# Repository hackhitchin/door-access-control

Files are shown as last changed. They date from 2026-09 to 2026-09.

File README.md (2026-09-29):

# Door Access Controller

Arduino Nano based door-control firmware for the Hack Hitchin access-control
system.

The Nano does **not** authenticate RFID cards. Credential verification is
handled separately by the ESP-RFID Blue Board. The Nano is responsible for the
door-control state machine, sensor handling, timing and the Utopic lock
interface.

This project is being developed with an emphasis on:

- predictable behaviour;
- explicit failure handling;
- simple hardware interfaces;
- host-side automated testing;
- code that remains approachable to future hackspace maintainers.

> **Not yet ready for deployment on the real door.**
>
> The FSM/controller are under automated test and CI compiles the complete classic
> Nano target. Hardware bench test and installation validation are still to be
> completed.

## Architecture

The firmware is split into three layers:

```text
physical inputs / millis()
          |
          v
DoorController
- debounce
- edge qualification
- startup handling
- timeout generation
          |
          v
DoorFsm
- states
- transitions
- faults
- retry policy
          |
          v
LockCommand
          |
          v
Arduino GPIO / relays
```

The FSM contains door-control policy. The surrounding controller converts raw,
debounced inputs and elapsed time into FSM events. The `.ino` file is intended
to remain a thin Arduino hardware adapter.

## FSM

The state machine uses ETL `state_chart`.

States:

- `LockedClosed`
- `Unlocking`
- `UnlockRetryWait`
- `UnlockedClosed`
- `Locking`
- `LockRetryWait`
- `UnlockedOpen`
- `Disabled`
- `Error`

There is deliberately no normal `LockedOpen` state. The bolt sensor is only
considered reliable when the door is closed; door-open plus bolt-locked is
treated as a contradictory physical/sensor condition.

### Motor commands

Motor output is derived from FSM state:

```text
Locking    -> Lock
Unlocking  -> Unlock
everything else -> None
```

The lock and unlock outputs are never intentionally asserted together.

During a retry wait the command is `None`. Unlock retries wait 1 s; lock
retries use the configured 1/10/100/1000/10000 s back-off.

A release request received during an in-flight lock operation is queued. The
controller waits for that lock command to confirm or time out, then unlocks
instead of accepting the locked state or starting another lock retry.

## Faults

Current fault codes are:

- `DoorOpenBoltLocked`
- `LockFailed`
- `UnlockFailed`
- `DoorOpenTooLong`
- `InvalidMode`

Entering `Error` removes the lock/unlock motor command.

Faults are not persisted across reset. A fault that is still physically present
after reboot should be detected again from the current inputs.

Where the underlying fault clears and a valid physical state can be
reconstructed, the FSM can return to normal operation without retaining the old
fault.

## Operating modes

The planned three-position maintained key switch has two signal inputs:

```text
D8  Standard
D9  Open Night
```

with pull-ups and contacts that pull the selected input LOW.

Logical encoding:

```text
D8  D9
HIGH HIGH  Disabled
LOW  HIGH  Standard
HIGH LOW   Open Night
LOW  LOW   Invalid / wiring fault
```

`Disabled` currently means no electronic lock or unlock commands. In
particular, the exit button is currently ignored in Disabled mode; this remains
a behaviour item to revisit if required.

## Inputs

Current Nano signal map:

```text
D2  lock-state sensor       active LOW
D3  exit button             active LOW
D4  door-closed reed        active LOW
D7  BlueBoard RFID release  active LOW
D8  Standard-mode contact   active LOW
D9  Open-Night contact      active LOW
```

Debounce times:

```text
door          30 ms
bolt          20 ms
RFID          10 ms
exit button   30 ms
mode switch   1000 ms
```

RFID and exit-button requests intentionally have different boot behaviour:

- RFID already active at boot is ignored until it first becomes inactive;
- an exit button already held at boot is honoured when electronic control is
  enabled.

At power-up the complete raw input set must remain unchanged for 100 ms before
controller construction, but this qualification wait is capped at 2 s so a
chattering input cannot prevent boot indefinitely.

## Outputs

Current relay mapping:

```text
A3 -> RL4 -> Utopic puck T1 -> lock
A2 -> RL3 -> Utopic puck T2 -> unlock
A1 -> RL2 -> FAULT connector
A0 -> RL1 -> BlueBoard "Button" contacts
```

Driving A3 or A2 HIGH energises the corresponding relay and pulls the Utopic
puck input LOW.

The Arduino hardware adapter uses break-before-make when changing lock command:
after either motor relay is released, the opposite relay cannot energise for
250 ms. This dead time is retained across intermediate `None` commands.

The FAULT relay is active for any FSM fault and also after the second failed
lock attempt while the longer retry back-off continues. A later successful lock
clears this degraded indication.

## Timing

Current parameters:

```text
Standard auto-lock        5 s
Open Night period         2 h
door-open warning         30 s
maximum door-open time    5 min Standard / 2 h Open Night
lock attempt timeout      5 s
unlock attempt timeout    5 s
lock retry delays         1 s, 10 s, 100 s, 1000 s, 10000 s
maximum lock retries      5
unlock retry delay        1 s
maximum unlock retries    2
```

Retry counts are retries **after** the initial attempt. Locking now uses five
back-off retries; unlocking retains two 1 s retries.

Timing code uses unsigned `uint32_t` subtraction so it remains correct across
Arduino `millis()` rollover.

## Testing

Native host tests use Unity and run in GitHub Actions on Ubuntu.

The FSM test suite covers:

- normal transitions;
- explicit retry-wait states;
- manual lock/unlock;
- mode transitions;
- fault entry;
- retry exhaustion;
- fault recovery;
- representative end-to-end sequences;
- state/event safety checks.

The established FSM coverage is:

```text
lines       100%
functions   100%
branches    88.9% (combined FSM + controller measurement before review fixes)
```

The remaining uncovered branches are compiler-generated short-circuit paths
that correspond to unreachable/redundant state combinations. CI therefore
requires:

```text
lines       100%
functions   100%
branches    >= 88%
```

A separate controller/wrapper test suite exercises debounce, startup handling,
RFID boot qualification, timeout generation, stale-timer cancellation,
same-tick ordering and `millis()` rollover.

CI builds and runs the FSM and controller test executables before collecting
combined coverage, and separately compiles the complete sketch for a classic
Arduino Nano with pinned AVR-core and ETL versions.

Third-party Unity/ETL code and test sources are excluded from project coverage.

For controlled bench commissioning, defining `DOOR_SERIAL_DIAGNOSTICS=1` in the
sketch enables a compact 115200-baud status line once per second. It reports
time, numeric state/mode/fault/command values, fault indication and debounced
input levels. It is disabled by default; opening USB serial may reset the Nano
via DTR.

## Repository layout

The intended source layout is:

```text
door-access-control/
├── door-access-control.ino
├── src/
│   ├── controller_config.h
│   ├── controller_types.h
│   ├── debounce.h
│   ├── door_controller.cpp
│   ├── door_controller.h
│   ├── door_fsm.cpp
│   ├── door_fsm.h
│   └── pin_defs.h
├── test/
│   ├── test_all.cpp
│   ├── test_controller.cpp
│   └── test_helpers.h
├── docs/
├── reference/
├── hardware/
├── mechanical/
└── .github/
    └── workflows/
        └── tests.yml
```

There should be one canonical copy of each source file. The Arduino sketch
includes the files in `src/`; source files are not duplicated in a separate
Arduino directory.

## Dependencies

- Arduino Nano / ATmega328P
- Embedded Template Library (ETL), using `etl::state_chart`
- Unity test framework for native tests
- LCOV/GCOV for CI coverage

ETL is downloaded by the GitHub Actions test workflow. Unity is kept in the
repository under `third_party/unity`.

## Hardware still outside the firmware

The following are deliberately not part of the current door-control firmware:

- optional backup maglock;
- independent watchdog / monitoring system;
- email or remote fault notification;
- persistent fault history.

These should remain separate from the safety-critical FSM unless their
interfaces are explicitly defined and tested.

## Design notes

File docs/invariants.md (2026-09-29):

# Door Controller System Invariants

Status: Draft v1  
Project: Hitchin Hackspace door access system

This document defines properties that must remain true regardless of the
sequence of valid inputs, timing events, mode changes, retries, resets, or
manual operation.

These invariants are intended to become permanent requirements and direct
targets for automated tests.

The transition specification defines what the controller does in each state.
This document defines what the controller must never violate.

---

# 1. Output safety invariants

## INV-001 — Lock and unlock outputs are mutually exclusive

The controller must never command both lock and unlock simultaneously.

Formally:

    !(LOCK_COMMAND && UNLOCK_COMMAND)

With the current state model:

    LOCKING    -> LOCK only
    UNLOCKING  -> UNLOCK only
    all others -> neither

This should preferably be made impossible by the software representation, for
example with a single `LockCommand` enum rather than two independent booleans.

---

## INV-002 — Lock output is only active in `LOCKING`

T1 may only be asserted while the FSM is in `LOCKING`.

Formally:

    lock_output_active <=> state == LOCKING

No stable state, Disabled state, or Error state may leave T1 asserted.

---

## INV-003 — Unlock output is only active in `UNLOCKING`

T2 may only be asserted while the FSM is in `UNLOCKING`.

Formally:

    unlock_output_active <=> state == UNLOCKING

No stable state, Disabled state, or Error state may leave T2 asserted.

---

## INV-004 — No motor command in `DISABLED`

While operating mode is Disabled, the controller must not intentionally issue
either electronic lock or unlock commands.

Formally:

    mode == Disabled -> LockCommand::None

This applies to RFID requests and, under the current first-pass policy, to the
internal exit button as well.

The exit-button behaviour in Disabled mode remains a TODO for final review.

---

## INV-005 — No motor command in `ERROR`

While the controller is in `ERROR`, neither T1 nor T2 may remain asserted.

Formally:

    state == ERROR -> LockCommand::None

Fault handling must not blindly operate the lock unless a future explicitly
specified recovery mechanism is added.

---

# 2. Door-position safety invariants

## INV-006 — Never intentionally begin locking while the door is known open

The controller must not enter `LOCKING` while `door_closed == false`.

Formally:

    transition_to(LOCKING) -> door_closed == true

If the door opens while already locking, the lock command must be aborted
immediately and the controller must leave `LOCKING`.

---

## INV-007 — Door opening aborts active motor commands

If `DOOR_OPENED` occurs while in either transient state:

    LOCKING
    UNLOCKING

the active T1/T2 command must be released and the controller must transition to:

    UNLOCKED_OPEN

This prevents continued motor actuation while the door is physically open.

---

## INV-008 — `LOCKED_OPEN` is not a valid normal state

The FSM must never treat:

    door_closed == false
    bolt_locked == true

as a normal stable state.

This combination must be treated as a sensor/physical fault.

Reason:

The bolt-state sensor is only considered meaningful when the door is closed and
aligned with the frame. A bolt indication while the door is open is therefore
ambiguous and must not be used to infer a trustworthy `LOCKED_OPEN` condition.

---

## INV-009 — No automatic recovery actuation from an ambiguous open-door fault

The controller must not automatically issue an unlock command solely because:

    door is open
    bolt sensor reports locked
    an open-door timeout expires

The historical automatic-unlock recovery paths are deliberately excluded from
the design because the physical condition cannot be identified reliably enough.

---

# 3. Release-request invariants

## INV-010 — Valid release request takes priority over an in-flight lock operation

In Standard mode, either of the following valid requests:

    RFID_RELEASE_REQUEST
    EXIT_BUTTON_REQUEST

must guarantee that the controller releases the door after any already-issued
lock command reaches a known conclusion.

If received while in `LOCKING`, the request is queued. The controller keeps the
current lock attempt active until `BOLT_LOCKED` or `LOCK_TIMEOUT`, then enters
`UNLOCKING` instead of accepting the locked state or starting another lock
retry. A request received in `LOCK_RETRY_WAIT` is similarly queued and prevents
the next lock retry.

This avoids depending on whether the Utopic/HAI aborts or completes a previously
issued one-shot lock command when T1 is released. Open Night selection uses the
same pending-release behaviour during a lock operation.

---

## INV-011 — RFID input active at boot is not a new access event

An RFID release input already active during startup must not generate an
`RFID_RELEASE_REQUEST`.

The input remains disarmed until it has first been observed inactive.

Only a subsequent inactive-to-active transition may generate a valid RFID
release event.

This prevents the tail end of an access-controller pulse from causing a new
unlock after a Nano restart.

---

## INV-012 — Exit button held at boot remains a valid request

Unlike the RFID signal, an internal exit button already active during startup
must be honoured when electronic operation is enabled.

This distinction is intentional and must remain explicit in the implementation
and tests.

---

## INV-013 — A new release request while already unlocked restarts the Standard auto-lock timer

In Standard mode, while in `UNLOCKED_CLOSED`:

    RFID_RELEASE_REQUEST
    EXIT_BUTTON_REQUEST

must restart the full `auto_lock_time`.

A new legitimate release request must not inherit a nearly-expired auto-lock
timer.

---

# 4. Mode invariants

## INV-014 — Exactly one logical operating mode exists at a time

The controller must expose exactly one logical operating mode:

    Disabled
    Standard
    OpenNight
    Invalid

The physical key-switch input combination must be decoded before being passed
to the FSM.

The FSM must not operate on two independent mode booleans.

---

## INV-015 — Invalid key-switch combination is never silently interpreted as a valid mode

Any electrical input combination not explicitly assigned to:

    Disabled
    Standard
    OpenNight

must decode as:

    Invalid

It must not silently fall back to Standard or Open Night.

---

## INV-016 — Selecting Open Night while locked causes release

If:

    state == LOCKED_CLOSED
    mode changes to OpenNight

the controller must transition toward:

    UNLOCKING

Open Night selection itself is therefore an intentional release request.

---

## INV-017 — Open Night to Standard gets a fresh Standard auto-lock interval

If the controller is already unlocked and operating mode changes:

    OpenNight -> Standard

a fresh Standard `auto_lock_time` must begin.

The controller must not lock immediately solely because of the mode change.

---

# 5. Retry and timeout invariants

## INV-018 — Every lock/unlock attempt is time bounded

An individual lock or unlock attempt may not hold its command indefinitely.

Maximum single-attempt duration:

    LOCK_TIME_MS
    UNLOCK_TIME_MS

A timeout must either:

- begin the defined retry sequence; or
- enter `ERROR` when retry allowance is exhausted.

---

## INV-019 — Retry count means retries after the initial attempt

Retry counters must not include the initial attempt.

For locking, `MAX_LOCK_RETRIES = 5`, so the maximum sequence is:

    initial attempt
    retry 1
    retry 2
    retry 3
    retry 4
    retry 5
    ERROR

For unlocking, `MAX_UNLOCK_RETRIES = 2`, so the maximum sequence is:

    initial attempt
    retry 1
    retry 2
    ERROR

This semantic must be consistent in implementation, diagnostics, and tests.

---

## INV-020 — Retry limit is finite

The controller must never retry lock or unlock indefinitely.

After the configured maximum number of retries, failure must lead to `ERROR`.

---

## INV-021 — Successful actuation clears the corresponding retry counter

Successful transition to:

    LOCKED_CLOSED

must clear the lock retry counter.

Successful transition from `UNLOCKING` after `BOLT_UNLOCKED` must clear the
unlock retry counter.

A later operation therefore starts with zero retries consumed.

---

## INV-022 — Retry commands are separated by explicit output-off wait states

After a failed attempt the controller must enter:

    LOCK_RETRY_WAIT

or:

    UNLOCK_RETRY_WAIT

for the configured delay for that attempt. Lock retry waits use the defined
1/10/100/1000/10000 s back-off; unlock retry waits use `RETRY_DELAY_MS` (1 s).

During either retry-wait state:

    LockCommand == None

The controller must not implement retries as one uninterrupted assertion of the
same command.

---

# 6. Startup and reset invariants

## INV-023 — Startup begins with no lock command active

Before the controller has reconstructed the physical state:

    LockCommand == None

No lock or unlock output may be asserted merely because the microcontroller has
booted.

---

## INV-024 — Startup does not restore transient FSM states

A reset must not attempt to restore:

    LOCKING
    UNLOCKING

from historical controller state.

Startup reconstructs behaviour from current physical inputs and current
operating mode.

---

## INV-025 — Historical faults are not persisted by the FSM

A controller reset discards historical transient fault state.

After reboot:

- current inputs are re-evaluated;
- a currently-existing fault is raised again;
- a fault that no longer exists is not recreated merely because it happened
  before reset.

Persistent event/fault logging, if desired, belongs to the external watchdog or
monitoring system.

---

## INV-026 — Standard startup with closed/unlocked door locks immediately

If startup finds:

    mode == Standard
    door_closed == true
    bolt_locked == false
    exit button not requesting release

the controller must begin `LOCKING` immediately.

It must not wait for the normal Standard `auto_lock_time`.

An RFID input already active at boot remains subject to INV-011 and does not
prevent this.

---

## INV-027 — Startup with an open door does not command locking

If startup finds:

    door_closed == false

the controller must not command `LOCKING`.

If the bolt sensor also reports locked, the condition is handled as a fault
rather than as a reason to operate the motor.

---

# 7. State-consistency invariants

## INV-028 — `LOCKED_CLOSED` requires closed door and locked indication

Whenever the controller is in `LOCKED_CLOSED`:

    door_closed == true
    bolt_locked == true

If either condition ceases to be true, the controller must process the
corresponding event and leave that state.

---

## INV-029 — `UNLOCKED_CLOSED` requires closed door and no locked indication

Whenever the controller is in `UNLOCKED_CLOSED`:

    door_closed == true
    bolt_locked == false

If the door opens, transition to `UNLOCKED_OPEN`.

If the bolt becomes locked, treat it as manual locking and transition to
`LOCKED_CLOSED`.

---

## INV-030 — `UNLOCKED_OPEN` requires the door to be open

Whenever the controller is in `UNLOCKED_OPEN`:

    door_closed == false

When the door closes, the controller must leave `UNLOCKED_OPEN` and apply the
policy appropriate to the current operating mode.

---

# 8. Fault invariants

## INV-031 — Faults auto-clear only when the underlying condition is gone

The default fault policy is auto-clear.

A fault may only clear when:

- the condition that caused it is no longer present; and
- the controller can reconstruct a valid stable state.

Auto-clear must not merely occur because a timeout elapsed or another unrelated
event occurred.

---

## INV-032 — Fault cause remains distinguishable while in `ERROR`

While the controller is in `ERROR`, the cause of the current fault must remain
available to diagnostics as a distinct fault code or equivalent status value.

Different causes must not be collapsed into an indistinguishable generic error
inside the controller if doing so would prevent useful diagnosis.

The final fault catalogue is defined separately.

---

# 9. Timing invariants

## INV-033 — Time comparisons must remain correct across `millis()` wraparound

All timer-expiry calculations must use unsigned wraparound-safe arithmetic.

For example:

```cpp
if ((uint32_t)(now - started_at) >= timeout) {
    ...
}
```

The implementation must not rely on:

```cpp
now >= started_at + timeout
```

where wraparound could break the comparison.

This invariant must have an explicit automated test.

---

## INV-034 — One timer expiry may only affect the operation it belongs to

Stale timer events from a previous state must not cause transitions in a new
state.

For example:

- an old `LOCK_TIMEOUT` must not affect `UNLOCKED_CLOSED`;
- an old `AUTO_LOCK_TIMEOUT` must not unexpectedly trigger after entering Open
  Night;
- an old `OPEN_TIMEOUT` must not affect a newly closed door.

Timers must therefore be cancelled, invalidated, or associated with the state /
operation instance that created them.

---

# 10. Implementation/test requirements derived from the invariants

The automated test suite should include:

- an assertion of INV-001 after every tested event;
- exhaustive state/event tests for all legal FSM states;
- explicit checks that stable-state sensor requirements remain true;
- tests of every mode transition;
- tests for RFID-at-boot and exit-button-at-boot;
- tests for door opening during both `LOCKING` and `UNLOCKING`;
- tests that retries stop at the configured maximum;
- tests that retry counters have the agreed semantics;
- tests that retry output is deasserted during `RETRY_DELAY_MS`;
- tests that stale timer events cannot affect later states;
- tests across `millis()` wraparound;
- startup tests for every combination of:
  - operating mode;
  - door sensor;
  - bolt sensor;
  - exit-button state;
  - RFID input initial state.

Where practical, invariants should also be expressed as runtime assertions in
the native test build so that long event-sequence and fuzz/property tests fail
immediately when an invariant is violated.

---

# 11. Deliberately not defined here

The following belong in other documents:

- exact transition-by-transition behaviour: `transitions.md`;
- timing/retry values: `parameters.md`;
- exact fault catalogue: `faults.md`;
- hardware pin allocation: `pin_defs.h`;
- electrical polarity and input conditioning;
- backup maglock policy;
- watchdog/email monitoring architecture;
- final decision on exit-button behaviour while Disabled.

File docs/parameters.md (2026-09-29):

# Door Controller Parameters

Status: Draft v1  
Project: Hitchin Hackspace door access system

This document defines the initial configurable timing and retry values used by
the door-controller FSM.

These are starting values for implementation and testing. The lock-motion
timings should be measured on the installed hardware and adjusted if required.

---

# 1. Initial values

| Parameter | Initial value | Purpose |
|---|---:|---|
| `AUTO_LOCK_TIME_MS` | 5,000 ms | Delay before relocking in Standard mode |
| `OPEN_TIMEOUT_MS` | 30,000 ms | Door-open warning/diagnostic threshold |
| `MAX_OPEN_TIMEOUT_MS` | 300,000 ms | Standard-mode door-open duration that raises an error |
| `OPEN_NIGHT_MAX_OPEN_TIMEOUT_MS` | 7,200,000 ms | Open Night door-open duration that raises an error |
| `OPEN_NIGHT_TIME_MS` | 7,200,000 ms | Open Night release duration |
| `LOCK_TIME_MS` | 5,000 ms | Maximum duration of one lock attempt |
| `UNLOCK_TIME_MS` | 5,000 ms | Maximum duration of one unlock attempt |
| `RETRY_DELAY_MS` | 1,000 ms | Delay between failed unlock attempts |
| lock retry back-off | 1 s, 10 s, 100 s, 1,000 s, 10,000 s | Delays before lock retries 1-5 |
| `MAX_LOCK_RETRIES` | 5 | Retries after the initial lock attempt |
| `MAX_UNLOCK_RETRIES` | 2 | Retries after the initial unlock attempt |
| `RELAY_REVERSAL_DEADTIME_MS` | 250 ms | Minimum off-time before energising the opposite relay |
| `STARTUP_INPUT_STABLE_MS` | 100 ms | Required unchanged startup input interval |
| `STARTUP_INPUT_TIMEOUT_MS` | 2,000 ms | Maximum startup qualification wait |

---

# 2. Suggested firmware constants

```cpp
constexpr uint32_t AUTO_LOCK_TIME_MS = 5000UL;
constexpr uint32_t OPEN_TIMEOUT_MS = 30000UL;
constexpr uint32_t MAX_OPEN_TIMEOUT_MS = 300000UL;
constexpr uint32_t OPEN_NIGHT_MAX_OPEN_TIMEOUT_MS = 7200000UL;
constexpr uint32_t OPEN_NIGHT_TIME_MS = 7200000UL;
constexpr uint32_t LOCK_TIME_MS = 5000UL;
constexpr uint32_t UNLOCK_TIME_MS = 5000UL;
constexpr uint32_t RETRY_DELAY_MS = 1000UL;
constexpr uint8_t MAX_LOCK_RETRIES = 5U;
constexpr uint8_t MAX_UNLOCK_RETRIES = 2U;
```

---

# 3. Retry semantics

The retry counters count retries, not total attempts.

Locking uses five retries after the initial attempt. If the bolt sensor never
confirms locked, the controller releases T1 between attempts and waits:

    1 s -> 10 s -> 100 s -> 1,000 s -> 10,000 s

After the fifth retry attempt times out, the controller enters
`ERROR / LockFailed`. Door opening, a release request, Disabled mode, or a
successful bolt-locked indication interrupts the retry sequence. A valid release
request during `LOCKING` or `LOCK_RETRY_WAIT` is queued and suppresses any
further lock retry; the controller proceeds to `UNLOCKING` when the current
lock operation reaches a known completion/timeout point.

Unlocking retains two retries with a 1 s wait between attempts.

A successful lock/unlock clears the corresponding retry counter.

# 4. Standard mode timing

In Standard mode:

- a new valid release request unlocks the door;
- while `UNLOCKED_CLOSED`, each new RFID or exit-button request restarts
  `AUTO_LOCK_TIME_MS`;
- switching from Open Night to Standard while already unlocked starts a fresh
  `AUTO_LOCK_TIME_MS`;
- when `AUTO_LOCK_TIME_MS` expires, locking begins if no other event prevents it.

`OPEN_TIMEOUT_MS` is a warning/diagnostic threshold only.

It does not command the lock.

`MAX_OPEN_TIMEOUT_MS` raises an open-too-long fault in Standard mode.

---

# 5. Open Night timing

Selecting Open Night while locked starts unlocking immediately.

The initial Open Night duration is:

    2 hours

represented by:

    OPEN_NIGHT_TIME_MS = 7,200,000

While Open Night is active, the maximum continuous door-open interval is also
2 hours (`OPEN_NIGHT_MAX_OPEN_TIMEOUT_MS`). The 30 s warning remains available
for diagnostics.

---

# 6. Lock and unlock attempt timing

Each lock attempt may hold T1 active for up to:

    5 seconds

Each unlock attempt may hold T2 active for up to:

    5 seconds

These values are deliberately conservative starting values.

Before final deployment, measure normal lock and unlock times on the installed
Utopic hardware under representative conditions and confirm that the timeout
provides adequate margin without unnecessarily delaying fault detection.

---

# 7. Fault/reset policy related to parameters

Faults auto-clear when their underlying condition clears and the FSM can return
to a valid stable state.

Fault history is not persisted across reset.

Persistent historical logging, if required, is delegated to the external
watchdog/monitoring system.

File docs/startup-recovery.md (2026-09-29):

# Startup and recovery

Status: implemented behaviour, September 2026.

## Startup input qualification

After GPIO configuration, the Arduino adapter keeps all relay outputs off and waits until the complete input set has remained unchanged for 100 ms. Qualification is capped at 2 s so a permanently chattering input cannot prevent boot forever; on timeout the latest sample is used and the normal debounce/fault logic takes over.

Runtime mode changes use a 1000 ms stable period. This is intentional for the centre-off maintained key switch: a normal transition through the centre position should not publish a temporary `Disabled` mode unless the switch is actually left there for at least one second.

## Startup reconstruction

- Disabled is authoritative: startup enters `Disabled` and does not actuate, regardless of door/bolt sensor combination.
- Standard + closed + locked -> `LockedClosed`.
- Standard + closed + unlocked -> `Locking`, unless a held exit request immediately releases it.
- Open Night + closed + locked -> `Unlocking`.
- Open Night + closed + unlocked -> `UnlockedClosed`.
- Enabled + open + unlocked -> `UnlockedOpen`.
- Enabled + open + locked -> `Error / DoorOpenBoltLocked`.
- Invalid mode -> `Error / InvalidMode`, unless the physical contradiction has higher priority.

RFID active at boot is deliberately disarmed until it first becomes stably inactive. A held exit button is honoured when electronic control is enabled.

## Release during an in-flight lock command

A release request received during `Locking` or `LockRetryWait` is queued rather than immediately changing to `Unlocking`. This avoids declaring the door released while a previously issued one-shot lock command may still complete. When the in-flight lock confirms `BoltLocked`, times out, or a pending retry wait expires, the pending request takes priority and the FSM enters `Unlocking` rather than starting/accepting another lock operation.

Unlock completion remains level-sensitive: after an event genuinely enters `Unlocking`, the controller checks whether the stable bolt level is already unlocked and, if so, immediately supplies `BoltUnlocked`.

## Error recovery

Present-tense observable faults have priority while `Error` is active:

1. door open + bolt locked -> `DoorOpenBoltLocked`;
2. invalid mode -> `InvalidMode`;
3. otherwise a historical operation failure such as `LockFailed` or `UnlockFailed` is retained until a valid recovery transition occurs.

Fault history is not persisted across reset.

## Relay startup and reversal

Relay outputs are set LOW before their pins become outputs. Whenever an energised lock/unlock relay is released, its direction and release time are remembered. The opposite relay may not energise until 250 ms later, even if one or more explicit `None` commands occur in between. Reasserting the same direction does not require dead time.

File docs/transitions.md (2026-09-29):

# Door Controller Transition Specification

Status: Draft v1  
Project: Hitchin Hackspace door access system

This document defines the finite state machine behaviour of the Arduino Nano
door controller.

It is derived from the existing FSM diagram, with the following agreed updates:

- RFID/access-controller unlock requests and internal exit-button requests are
  treated as separate inputs.
- The controller has three operating modes:
  - Disabled
  - Standard
  - Open Night
- Selecting Open Night while locked immediately starts unlocking.
- T1 is held active for the whole `LOCKING` state.
- T2 is held active for the whole `UNLOCKING` state.
- Manual lock/unlock operation is permitted.
- `LOCKED_OPEN` is removed as a normal state because the bolt sensor is not
  considered trustworthy while the door is open.
- The historical struck-through automatic-unlock recovery paths for a
  manually-locked-open door are not implemented.
- An RFID release signal already active at startup is ignored until it clears.
- An exit button held during startup is honoured.
- If startup finds the door closed and unlocked in Standard mode, the controller
  locks immediately rather than waiting for `auto_lock_time`.

---

# 1. States

## 1.1 Stable states

### `LOCKED_CLOSED`

Door is closed and bolt sensor confirms locked.

Normal lock output:

    NONE

### `UNLOCKED_CLOSED`

Door is closed and bolt sensor does not indicate locked.

Normal lock output:

    NONE

### `UNLOCKED_OPEN`

Door is open.

The bolt sensor is not treated as a reliable indication of meaningful lock
state while the door is open.

Normal lock output:

    NONE

### `DISABLED`

Automatic/electronic lock control is disabled by the mode key switch.

Normal lock output:

    NONE

### `ERROR`

The controller has detected a fault requiring fault handling.

Normal lock output:

    NONE

Exact fault-latching and recovery behaviour is defined separately.

---

## 1.2 Transient states

### `LOCKING`

The controller is actively commanding the motorised lock to lock.

Output:

    hold T1 low

The command remains active until:

- the bolt sensor confirms locked;
- the door opens;
- a release request overrides the lock operation;
- the mode changes to Disabled;
- the operation times out and fault/retry logic acts.

### `UNLOCKING`

The controller is actively commanding the motorised lock to unlock.

Output:

    hold T2 low

The command remains active until:

- the bolt sensor confirms unlocked;
- the door opens;
- the mode changes to Disabled;
- the operation times out and fault/retry logic acts.

---

# 2. Events

External / physical events:

    RFID_RELEASE_REQUEST
    EXIT_BUTTON_REQUEST

    DOOR_OPENED
    DOOR_CLOSED

    BOLT_LOCKED
    BOLT_UNLOCKED

    MODE_DISABLED
    MODE_STANDARD
    MODE_OPEN_NIGHT
    MODE_INVALID

Timer / internal events:

    AUTO_LOCK_TIMEOUT
    OPEN_TIMEOUT
    MAX_OPEN_TIMEOUT

    LOCK_TIMEOUT
    UNLOCK_TIMEOUT

---

# 3. Output rule

The lock command is determined primarily by controller state:

| State | Output |
|---|---|
| `LOCKING` | hold T1 low |
| `UNLOCKING` | hold T2 low |
| `LOCK_RETRY_WAIT` | no lock command |
| `UNLOCK_RETRY_WAIT` | no lock command |
| all other states | no lock command |

LOCK and UNLOCK must never be asserted simultaneously.

---

# 4. Runtime transition table

## 4.1 `LOCKED_CLOSED`

| Event | Guard | Action | Next state | Notes |
|---|---|---|---|---|
| `RFID_RELEASE_REQUEST` | mode != Disabled | begin unlock | `UNLOCKING` | Access-controller request |
| `EXIT_BUTTON_REQUEST` | mode != Disabled | begin unlock | `UNLOCKING` | Internal exit request |
| `BOLT_UNLOCKED` | — | none | `UNLOCKED_CLOSED` | Manual unlock |
| `DOOR_OPENED` | bolt still reports locked | record sensor/physical fault | `ERROR` | Door-open + bolt-locked is not a trusted physical state |
| `MODE_DISABLED` | — | none | `DISABLED` | |
| `MODE_OPEN_NIGHT` | — | begin unlock | `UNLOCKING` | Open Night selection immediately unlocks |
| `MODE_STANDARD` | already Standard | none | `LOCKED_CLOSED` | no-op |
| `MODE_INVALID` | — | record mode fault | `ERROR` | proposed fault handling |

---

## 4.2 `UNLOCKING`

Output while in state:

    hold T2 low

| Event | Guard | Action | Next state | Notes |
|---|---|---|---|---|
| `BOLT_UNLOCKED` | — | release T2; clear unlock retry count | `UNLOCKED_CLOSED` | Successful unlock |
| `UNLOCK_TIMEOUT` | retries remain | release T2; increment retry count; start retry-delay timer | `UNLOCK_RETRY_WAIT` | Maximum 2 retries after initial attempt |
| `UNLOCK_TIMEOUT` | retries exhausted | release T2; record unlock fault | `ERROR` | |
| `DOOR_OPENED` | — | release T2 immediately | `UNLOCKED_OPEN` | Door opening aborts the active unlock command |
| `RFID_RELEASE_REQUEST` | — | none | `UNLOCKING` | Already unlocking |
| `EXIT_BUTTON_REQUEST` | — | none | `UNLOCKING` | Already unlocking |
| `MODE_DISABLED` | — | release T2 | `DISABLED` | |
| `MODE_OPEN_NIGHT` | — | continue unlock | `UNLOCKING` | |
| `MODE_STANDARD` | — | continue unlock | `UNLOCKING` | |
| `MODE_INVALID` | — | release T2; record mode fault | `ERROR` | |
| `BOLT_LOCKED` | — | none | `UNLOCKING` | Still waiting for unlock |

## 4.2a `UNLOCK_RETRY_WAIT`

Output while in state:

    none

| Event | Guard | Action | Next state | Notes |
|---|---|---|---|---|
| `RETRY_DELAY_ELAPSED` | — | restart unlock attempt | `UNLOCKING` | T2 is reasserted on entry to `UNLOCKING` |
| `BOLT_UNLOCKED` | — | clear unlock retry count | `UNLOCKED_CLOSED` | Mechanism may finish moving after T2 is released |
| `DOOR_OPENED` | — | clear unlock retry count | `UNLOCKED_OPEN` | Abort retry sequence |
| `MODE_DISABLED` | — | clear unlock retry count | `DISABLED` | |
| `MODE_OPEN_NIGHT` | — | none | `UNLOCK_RETRY_WAIT` | Continue retry sequence |
| `MODE_STANDARD` | — | none | `UNLOCK_RETRY_WAIT` | Continue retry sequence |

---

## 4.3 `UNLOCKED_CLOSED`

| Event | Guard | Action | Next state | Notes |
|---|---|---|---|---|
| `DOOR_OPENED` | — | start / continue open timing | `UNLOCKED_OPEN` | |
| `BOLT_LOCKED` | — | none | `LOCKED_CLOSED` | Manual lock |
| `AUTO_LOCK_TIMEOUT` | mode == Standard | begin lock | `LOCKING` | |
| `RFID_RELEASE_REQUEST` | mode == Standard | restart `auto_lock_time` | `UNLOCKED_CLOSED` | Already unlocked; grant a fresh unlocked interval |
| `EXIT_BUTTON_REQUEST` | mode == Standard | restart `auto_lock_time` | `UNLOCKED_CLOSED` | Already unlocked; grant a fresh unlocked interval |
| `MODE_DISABLED` | — | none | `DISABLED` | |
| `MODE_OPEN_NIGHT` | — | cancel / extend Standard auto-lock behaviour | `UNLOCKED_CLOSED` | Open Night keeps door released |
| `MODE_STANDARD` | from Open Night | start fresh `auto_lock_time` | `UNLOCKED_CLOSED` | Lock when the Standard timer expires |
| `MODE_INVALID` | — | record mode fault | `ERROR` | |

---

## 4.4 `LOCKING`

Output while in state:

    hold T1 low

| Event | Guard | Action | Next state | Notes |
|---|---|---|---|---|
| `BOLT_LOCKED` | release pending | release T1; clear lock retry count; begin unlock | `UNLOCKING` | A real unlock command follows the completed in-flight lock |
| `BOLT_LOCKED` | no release pending | release T1; clear lock retry count | `LOCKED_CLOSED` | Successful lock |
| `LOCK_TIMEOUT` | release pending | release T1; clear lock retry count; begin unlock | `UNLOCKING` | Pending release suppresses another lock retry |
| `LOCK_TIMEOUT` | retries remain | release T1; increment retry count; start back-off timer | `LOCK_RETRY_WAIT` | Up to 5 retries after initial attempt |
| `LOCK_TIMEOUT` | retries exhausted | release T1; record lock fault | `ERROR` | |
| `DOOR_OPENED` | — | release T1 immediately | `UNLOCKED_OPEN` | Abort active lock command |
| `RFID_RELEASE_REQUEST` | mode != Disabled | mark release pending; keep current lock attempt | `LOCKING` | Do not depend on mid-travel abort behaviour |
| `EXIT_BUTTON_REQUEST` | mode != Disabled | mark release pending; keep current lock attempt | `LOCKING` | Do not depend on mid-travel abort behaviour |
| `MODE_DISABLED` | — | release T1 | `DISABLED` | |
| `MODE_OPEN_NIGHT` | — | mark release pending; keep current lock attempt | `LOCKING` | Unlock follows completion/timeout |
| `MODE_STANDARD` | — | continue lock | `LOCKING` | |
| `MODE_INVALID` | — | release T1; record mode fault | `ERROR` | |
| `BOLT_UNLOCKED` | — | none | `LOCKING` | Still waiting for lock |

## 4.4a `LOCK_RETRY_WAIT`

Output while in state:

    none

| Event | Guard | Action | Next state | Notes |
|---|---|---|---|---|
| `RETRY_DELAY_ELAPSED` | release pending | clear lock retry count; begin unlock | `UNLOCKING` | Do not start another lock retry |
| `RETRY_DELAY_ELAPSED` | no release pending | restart lock attempt | `LOCKING` | T1 is reasserted on entry to `LOCKING` |
| `BOLT_LOCKED` | release pending | clear lock retry count; begin unlock | `UNLOCKING` | Late lock completion is followed by a real unlock command |
| `BOLT_LOCKED` | no release pending | clear lock retry count | `LOCKED_CLOSED` | Mechanism may finish moving after T1 is released |
| `DOOR_OPENED` | — | clear lock retry count | `UNLOCKED_OPEN` | Abort retry sequence |
| `RFID_RELEASE_REQUEST` | mode != Disabled | mark release pending | `LOCK_RETRY_WAIT` | Suppress the next lock retry |
| `EXIT_BUTTON_REQUEST` | mode != Disabled | mark release pending | `LOCK_RETRY_WAIT` | Suppress the next lock retry |
| `MODE_DISABLED` | — | clear lock retry count | `DISABLED` | |
| `MODE_OPEN_NIGHT` | — | mark release pending | `LOCK_RETRY_WAIT` | Suppress the next lock retry |

---

## 4.5 `UNLOCKED_OPEN`

The bolt sensor is not used to establish a normal `LOCKED_OPEN` state while the
door is open.

| Event | Guard | Action | Next state | Notes |
|---|---|---|---|---|
| `DOOR_CLOSED` | mode == Standard | begin / schedule Standard relock behaviour | `UNLOCKED_CLOSED` | |
| `DOOR_CLOSED` | mode == OpenNight | remain released under Open Night policy | `UNLOCKED_CLOSED` | |
| `DOOR_CLOSED` | mode == Disabled | none | `DISABLED` | |
| `BOLT_LOCKED` | door still open | record sensor/physical fault | `ERROR` | Door-open + bolt-locked is treated as fault |
| `MAX_OPEN_TIMEOUT` | — | record open-too-long fault | `ERROR` | |
| `OPEN_TIMEOUT` | — | no automatic lock actuation | `UNLOCKED_OPEN` | Historical automatic-unlock recovery was rejected |
| `RFID_RELEASE_REQUEST` | — | none | `UNLOCKED_OPEN` | Already released |
| `EXIT_BUTTON_REQUEST` | — | none | `UNLOCKED_OPEN` | Already released |
| `MODE_DISABLED` | — | none | `DISABLED` | |
| `MODE_STANDARD` | — | apply Standard open-time limits | `UNLOCKED_OPEN` | |
| `MODE_OPEN_NIGHT` | — | apply Open Night open-time limits | `UNLOCKED_OPEN` | |
| `MODE_INVALID` | — | record mode fault | `ERROR` | |

---

## 4.6 `DISABLED`

Disabled mode performs no electronic lock/unlock action.

RFID and exit-button requests are ignored in this mode.

| Event | Guard | Action | Next state | Notes |
|---|---|---|---|---|
| `RFID_RELEASE_REQUEST` | — | ignore | `DISABLED` | |
| `EXIT_BUTTON_REQUEST` | — | ignore | `DISABLED` | TODO: revisit/confirm before release |
| `MODE_STANDARD` | door closed, bolt locked | none | `LOCKED_CLOSED` | Reconstruct physical state |
| `MODE_STANDARD` | door closed, bolt unlocked | begin lock immediately | `LOCKING` | |
| `MODE_STANDARD` | door open | none | `UNLOCKED_OPEN` | Bolt state not trusted while open |
| `MODE_OPEN_NIGHT` | door closed, bolt locked | begin unlock | `UNLOCKING` | Open Night selection immediately releases door |
| `MODE_OPEN_NIGHT` | door closed, bolt unlocked | none | `UNLOCKED_CLOSED` | |
| `MODE_OPEN_NIGHT` | door open | none | `UNLOCKED_OPEN` | |
| `MODE_INVALID` | — | record mode fault | `ERROR` | |
| `BOLT_LOCKED` / `BOLT_UNLOCKED` | — | update observed physical condition only | `DISABLED` | No electronic actuation |
| `DOOR_OPENED` / `DOOR_CLOSED` | — | update observed physical condition only | `DISABLED` | No electronic actuation |

---

## 4.7 `ERROR`

The exact fault model is defined separately.

General behaviour:

- stop T1/T2 actuation;
- retain/report the fault cause;
- do not blindly attempt corrective motor movement;
- allow startup/recovery logic to re-evaluate physical state after reset.

| Event | Guard | Action | Next state | Notes |
|---|---|---|---|---|
| normal request | fault remains present | none | `ERROR` | |
| `MODE_DISABLED` | — | stop actuation | `DISABLED` | proposed operator recovery path |
| fault condition clears | auto-clear allowed for that fault | TBD | reconstructed stable state | fault policy TBD |
| controller reset | — | run startup reconstruction | startup path | old transient state is not restored |

---

# 5. Removed `LOCKED_OPEN` state

The previous FSM diagram contained a `lock: locked / door: open` state.

This state is removed from the revised FSM.

Reason:

- the lock-state sensor is only considered meaningful when the door is closed
  and aligned with the frame;
- therefore `door open + bolt locked` cannot be treated as a trustworthy normal
  physical state;
- the same sensor combination could result from a manually extended bolt,
  sensor error, wiring error, or another abnormal condition;
- automatically operating the lock to recover from that ambiguous condition
  was judged too risky.

Accordingly:

    door open + bolt reports locked

is treated as a sensor / physical fault rather than a normal FSM state.

---

# 6. Removed historical automatic-unlock recovery

The previous FSM drawing contained struck-through transitions equivalent to:

    electronic unlock after open_timeout

and:

    electronic unlock after locked_open_timeout

These were intended to recover from a possible condition where the door had
been left open with the lock manually extended.

They are deliberately not implemented.

Reason:

- the controller cannot reliably determine that this specific condition exists;
- the same observed inputs can represent other abnormal/fault states;
- automatically operating the lock in an ambiguous physical condition could
  make the situation worse.

Therefore no automatic unlock is performed solely because an open-door timeout
expires.

`MAX_OPEN_TIMEOUT` may still produce an error/fault indication: 5 minutes in Standard mode and 2 hours in Open Night.

---

# 7. Startup / recovery behaviour

Startup does not restore transient controller states such as `LOCKING` or
`UNLOCKING`.

Instead, the controller reads the current physical inputs and reconstructs an
appropriate stable state.

RFID and exit-button startup semantics differ:

- an RFID release signal already active at boot is ignored until it returns
  inactive;
- an exit button already held at boot is honoured.

---

## 7.1 Startup reconstruction table

| Mode | Door | Bolt | Exit button held | RFID active at boot | Startup behaviour |
|---|---|---|---|---|---|
| Disabled | any | any | any | any | enter `DISABLED`; no lock actuation |
| Standard | closed | locked | no | ignored | enter `LOCKED_CLOSED` |
| Standard | closed | locked | yes | ignored | begin `UNLOCKING` |
| Standard | closed | unlocked | no | ignored | begin `LOCKING` immediately |
| Standard | closed | unlocked | yes | ignored | enter `UNLOCKED_CLOSED` |
| Standard | open | any | any | ignored | enter `UNLOCKED_OPEN`; if bolt reports locked, raise fault |
| Open Night | closed | locked | any | ignored | begin `UNLOCKING` |
| Open Night | closed | unlocked | any | ignored | enter `UNLOCKED_CLOSED` |
| Open Night | open | any | any | ignored | enter `UNLOCKED_OPEN`; if bolt reports locked, raise fault |
| Invalid | any | any | any | any | enter fault handling |

---

## 7.2 RFID input arming after boot

At startup:

    if RFID input is inactive:
        arm immediately

    if RFID input is active:
        ignore it
        remain disarmed until it becomes inactive

After the input has been observed inactive:

    the next inactive -> active transition
    generates RFID_RELEASE_REQUEST

This prevents the tail end of an ESP-RFID timed output pulse from being treated
as a new access request after a controller reboot.

---

# 8. Retry behaviour

## 8.1 Locking

On entry to `LOCKING`:

    assert T1
    start lock timeout

If a release request arrives during `LOCKING`, mark it pending and continue
the current attempt. On `BOLT_LOCKED` or `LOCK_TIMEOUT`, a pending release takes
priority and the controller enters `UNLOCKING` rather than accepting the locked
state or starting another lock retry. A release request received during
`LOCK_RETRY_WAIT` similarly suppresses the next lock retry.

Without a pending release, if `BOLT_LOCKED` occurs before timeout:

    release T1
    clear lock retry count
    enter LOCKED_CLOSED

If `LOCK_TIMEOUT` occurs and retries remain:

    release T1
    increment lock retry count
    enter LOCK_RETRY_WAIT

Lock retry waits use 1 s, 10 s, 100 s, 1,000 s and 10,000 s before retries
1 through 5. If the fifth retry attempt times out, record `LockFailed` and enter
`ERROR`. Retry counters count retries after the initial attempt.

---

## 8.2 Unlocking

On entry to `UNLOCKING`:

    assert T2
    start unlock timeout

If `BOLT_UNLOCKED` occurs before timeout:

    release T2
    clear unlock retry count
    enter UNLOCKED_CLOSED

If `UNLOCK_TIMEOUT` occurs and retries remain:

    release/restart command according to retry policy
    increment unlock retry count
    remain UNLOCKING

If retries are exhausted:

    release T2
    record unlock failure
    enter ERROR

Use a 1 s retry delay. Retry counters count retries after the initial attempt.

---

# 9. Operating-mode behaviour

## 9.1 Disabled

Disabled means:

- no electronic lock command;
- no electronic unlock command;
- RFID release requests ignored;
- exit-button requests ignored;
- physical inputs may still be monitored for status/diagnostics.

TODO:

- revisit/confirm whether exit-button requests should remain ignored in Disabled
  mode before final release.

---

## 9.2 Standard

Standard is normal access-controlled operation.

Typical behaviour:

- valid RFID request -> unlock;
- exit button -> unlock;
- after closure / unlocked dwell -> automatic relock;
- normal open-time limits apply.

Exact timing values are defined separately.

---

## 9.3 Open Night

Selecting Open Night while the door is locked immediately starts unlocking.

While in Open Night:

- the door remains released for the longer Open Night policy;
- Standard automatic-relock timing is not used;
- Open Night-specific timing limits may still apply.

Exact timing values are defined separately.

---

# 10. Timing and retry policy

The initial controller parameter values are defined in `parameters.md`.

The transition rules assume the following policy:

- `auto_lock_time` = 5 s
- `open_timeout` = 30 s
- `max_open_timeout` = 5 min
- Open Night duration = 2 h
- `lock_time` = 5 s
- `unlock_time` = 5 s
- maximum lock retries = 5, with 1/10/100/1000/10000 s back-off
- maximum unlock retries = 2
- unlock retry delay = 1 s

Retry counters count retries after the initial attempt. Locking therefore allows
the initial attempt plus five retries using the back-off above. Unlocking allows
the initial attempt plus two retries separated by 1 s waits.

A retry counter value of zero means no retries have yet occurred.

---

# 11. Fault clearing and reset policy

Faults auto-clear when their underlying fault condition no longer exists and
the controller can reconstruct a valid stable state.

No FSM fault history is persisted across controller reset.

On reset:

1. historical transient fault state is discarded;
2. current inputs are sampled;
3. startup state reconstruction is performed;
4. any currently-present fault is raised again from the observed inputs.

Persistent fault/event logging, if required, belongs in the external
watchdog/monitoring system rather than in the Nano FSM.

---

# 12. Open Night -> Standard transition

If the controller is unlocked when operating mode changes from Open Night to
Standard:

    start a fresh Standard auto_lock_time

The controller does not lock immediately solely because the mode changed.

If no release request or other event intervenes before the timer expires:

    begin LOCKING

---

# 13. Release request while already unlocked

A new RFID release request while in `UNLOCKED_CLOSED` restarts the Standard
`auto_lock_time`.

A new exit-button request while in `UNLOCKED_CLOSED` also restarts the Standard
`auto_lock_time`.

This ensures that each new legitimate release request receives a complete
unlocked interval rather than inheriting a nearly-expired timer.

In Open Night mode, these requests do not shorten the Open Night release period.

---

# 14. Remaining unresolved decision

The following item remains deliberately unresolved:

- Final confirmation of exit-button behaviour while `Disabled`.

Current first-pass behaviour is:

    Disabled -> ignore EXIT_BUTTON_REQUEST

This must be revisited before final release.

---

# 15. Future optional behaviour

The following are intentionally outside this first-pass FSM:

- backup maglock control;
- watchdog/email monitoring;
- local fault LED strategy;
- remote diagnostics;
- persistent fault logging.

These may consume controller state/fault information later without changing the
core physical state model unless explicitly required.

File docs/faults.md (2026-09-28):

# Door Controller Fault Catalogue

Status: Draft v1  
Project: Hitchin Hackspace door access system

This document defines the fault conditions recognised by the door-controller
FSM, the conditions that raise them, their required controller response, and
their auto-clear conditions.

Faults are separate from FSM states.

The FSM has a general:

    ERROR

state, while the controller also records the reason for entering that state as
a distinct fault code.

The first implementation should preserve the current fault cause for
diagnostics while the fault is active.

---

# 1. Fault handling principles

Unless explicitly stated otherwise:

1. Entering `ERROR` immediately removes any active T1/T2 command.
2. The controller does not automatically operate the lock while in `ERROR`.
3. Faults auto-clear when the underlying fault condition is gone and the
   controller can reconstruct a valid stable state.
4. Fault history is not persisted across Nano reset.
5. Persistent historical logging is the responsibility of the future external
   watchdog / monitoring system.
6. A reset does not itself "fix" a fault:
   if the same invalid condition still exists after startup, the fault is
   raised again.

---

# 2. Proposed fault-code representation

Suggested first-pass representation:

```cpp
enum class FaultCode : uint8_t {
    None = 0,

    DoorOpenBoltLocked,
    LockFailed,
    UnlockFailed,
    DoorOpenTooLong,
    InvalidMode
};
```

This deliberately starts small.

Additional codes should only be added when the controller can actually
distinguish the condition reliably.

Do not create speculative fault codes for physical causes that cannot be
separated from one another by the available sensors.

---

# 3. Fault catalogue

## FLT-001 — Door open while bolt reports locked

Code:

    FaultCode::DoorOpenBoltLocked

Raised when:

    door_closed == false
    bolt_locked == true

or when either of the following occurs:

- `DOOR_OPENED` while in `LOCKED_CLOSED`;
- `BOLT_LOCKED` while in `UNLOCKED_OPEN`.

Response:

    stop T1/T2
    enter ERROR

No automatic corrective lock/unlock command is issued.

Rationale:

The bolt-state sensor is considered trustworthy only while the door is closed
and aligned with the frame.

Therefore this observed combination does not prove that the lock is genuinely
in a normal "locked open" physical state.

Possible causes include:

- manually extended bolt while the door is open;
- bolt-sensor fault;
- door-sensor fault;
- wiring fault;
- unusual mechanical condition.

The controller cannot safely distinguish those causes.

Auto-clear condition:

    door_closed == true

and the resulting closed-door sensor combination corresponds to a valid stable
state:

    closed + locked   -> LOCKED_CLOSED
    closed + unlocked -> UNLOCKED_CLOSED

If the door remains open while `bolt_locked == true`, the fault remains active.

Historical note:

The previous FSM considered automatically commanding UNLOCK after an
open/locked timeout. That recovery was deliberately rejected because the
specific physical condition cannot be identified reliably enough.

---

## FLT-002 — Lock operation failed

Code:

    FaultCode::LockFailed

Raised when:

- the controller enters `LOCKING`;
- the bolt fails to reach the locked indication within `LOCK_TIME_MS`;
- the configured number of retries is exhausted.

With the current parameters:

    initial attempt
    retry 1
    retry 2
    -> fault

Response:

    release T1
    enter ERROR

Possible physical causes include:

- mechanical obstruction;
- door not aligned correctly;
- Utopic lock failure;
- 433 MHz interface failure;
- lock relay failure;
- bolt sensor failure;
- wiring failure.

The controller does not attempt to identify which physical cause produced the
failed operation.

Auto-clear condition:

If the bolt subsequently reports a valid stable state while the door is closed,
the fault may auto-clear and the physical state is reconstructed.

Examples:

    door closed + bolt locked
        -> LOCKED_CLOSED

    door closed + bolt unlocked
        -> UNLOCKED_CLOSED

A future policy may choose to immediately re-apply normal Standard/Open Night
behaviour after reconstruction.

The exhausted retry counter is cleared when the fault clears.

---

## FLT-003 — Unlock operation failed

Code:

    FaultCode::UnlockFailed

Raised when:

- the controller enters `UNLOCKING`;
- the bolt remains locked beyond `UNLOCK_TIME_MS`;
- the configured number of retries is exhausted.

With the current parameters:

    initial attempt
    retry 1
    retry 2
    -> fault

Response:

    release T2
    enter ERROR

Possible physical causes include:

- mechanical obstruction;
- Utopic lock failure;
- 433 MHz interface failure;
- unlock relay failure;
- bolt sensor failure;
- wiring failure.

The controller does not attempt to identify which physical cause produced the
failed operation.

Auto-clear condition:

If the bolt subsequently reports unlocked while the door is closed:

    door closed + bolt unlocked
        -> UNLOCKED_CLOSED

the fault may clear.

If the door opens and the bolt indication no longer represents a meaningful
physical lock state, normal open-door reconstruction/fault rules apply.

The exhausted retry counter is cleared when the fault clears.

---

## FLT-004 — Door open too long

Code:

    FaultCode::DoorOpenTooLong

Raised when:

    state == UNLOCKED_OPEN

and:

    MAX_OPEN_TIMEOUT_MS

expires.

Current initial threshold:

    5 minutes

Response:

    enter ERROR
    do not command the lock

`OPEN_TIMEOUT_MS` at 30 seconds is not itself a fault.

It is a warning / diagnostic threshold only.

Rationale:

The controller must not attempt the historical automatic-unlock recovery while
the door is open.

The timeout therefore records an abnormal prolonged-open condition without
blindly actuating the lock.

Auto-clear condition:

When the door closes and the controller can reconstruct a valid physical state.

For example:

    door closes + bolt unlocked
        -> UNLOCKED_CLOSED

Normal mode policy then resumes.

---

## FLT-005 — Invalid operating-mode input

Code:

    FaultCode::InvalidMode

Raised when the physical key-switch input combination does not decode to one
of:

    Disabled
    Standard
    OpenNight

Examples include an impossible combination such as both dedicated mode inputs
active simultaneously, depending on the final key-switch wiring.

Response:

    stop T1/T2
    enter ERROR

The invalid combination must never be silently interpreted as Standard or Open
Night.

Auto-clear condition:

When the key-switch inputs again decode to a valid mode.

The controller then reconstructs the appropriate physical state and applies the
selected mode policy.

---

# 4. Conditions that are NOT faults

The following are intentionally not faults.

## 4.1 Manual unlock

If:

    LOCKED_CLOSED
    bolt_locked changes true -> false

without an electronic unlock command, this is treated as:

    manual unlock

and transitions to:

    UNLOCKED_CLOSED

---

## 4.2 Manual lock

If:

    UNLOCKED_CLOSED
    bolt_locked changes false -> true

without an electronic lock command, this is treated as:

    manual lock

and transitions to:

    LOCKED_CLOSED

---

## 4.3 Door opens during `LOCKING`

This is not itself a fault.

Required behaviour:

    release T1
    transition to UNLOCKED_OPEN

If the bolt sensor simultaneously produces an invalid open-door locked
indication, FLT-001 may then be raised.

---

## 4.4 Door opens during `UNLOCKING`

This is not itself a fault.

Required behaviour:

    release T2
    transition to UNLOCKED_OPEN

Again, if the resulting sensor combination is contradictory, FLT-001 applies.

---

## 4.5 `OPEN_TIMEOUT_MS` expires

The initial 30-second open timeout is not an ERROR condition.

It exists for:

- diagnostics;
- future watchdog notification;
- possible local warning indication.

Only `MAX_OPEN_TIMEOUT_MS` currently raises FLT-004.

---

## 4.6 RFID input active at startup

An RFID input already active when the Nano boots is not a fault.

It is ignored until the input first returns inactive.

This is deliberate startup qualification, not error handling.

---

## 4.7 Exit button held at startup

An exit button held during startup is not a fault.

When electronic operation is enabled, it is treated as a valid release request.

---

# 5. Fault priority

The first implementation does not require simultaneous multi-fault reporting.

If more than one fault condition is observable at the same time, the controller
may record one primary `FaultCode`.

Suggested priority:

1. `DoorOpenBoltLocked`
2. `InvalidMode`
3. active operation failure (`LockFailed` / `UnlockFailed`)
4. `DoorOpenTooLong`

Reasoning:

- contradictory physical sensor state should take priority over inferred
  operation outcomes;
- invalid operator-mode wiring prevents a reliable control policy;
- lock/unlock operation failures are then reported;
- prolonged-open timing is lower priority than contradictory hardware state.

A future watchdog may independently monitor raw inputs and report multiple
simultaneous diagnostic conditions even if the Nano FSM keeps only one primary
fault code.

---

# 6. Auto-clear rules

Faults auto-clear by default.

Auto-clear must be based on the underlying condition becoming valid, not merely
on time passing.

| Fault | Auto-clear condition |
|---|---|
| `DoorOpenBoltLocked` | sensor combination becomes physically valid |
| `LockFailed` | valid closed-door lock state becomes observable |
| `UnlockFailed` | valid unlocked state becomes observable |
| `DoorOpenTooLong` | door closes into a valid state |
| `InvalidMode` | key-switch inputs decode to a valid mode |

After auto-clear:

1. clear the current `FaultCode`;
2. clear any associated exhausted retry counter;
3. reconstruct the stable state from current inputs;
4. apply current operating-mode policy.

---

# 7. Reset behaviour

Fault codes are not persisted in EEPROM.

On reset:

    FaultCode = None

until startup evaluation identifies a current fault.

Examples:

A previous `LockFailed` followed by a reset with:

    door closed
    bolt locked

starts normally as:

    LOCKED_CLOSED

A reset with:

    door open
    bolt locked

raises:

    DoorOpenBoltLocked

again because the fault condition is still observable.

---

# 8. Diagnostics interface

The controller should make at least the following available to future local or
remote diagnostics:

```cpp
struct ControllerStatus {
    State state;
    FaultCode fault;
    uint8_t lockRetries;
    uint8_t unlockRetries;
};
```

The diagnostic interface must not be required for correct door operation.

Potential future consumers include:

- local error LED(s);
- existing FAULT relay;
- serial diagnostics;
- independent watchdog controller;
- email / remote alert system.

---

# 9. Future faults not yet justified

Do not add the following as first-pass FSM faults unless additional hardware or
diagnostics make them independently detectable:

- door sensor failed;
- bolt sensor failed;
- Utopic lock failed;
- 433 MHz transmitter failed;
- relay failed;
- cable disconnected;
- motor jammed.

At present these may produce observable symptoms such as:

    DoorOpenBoltLocked
    LockFailed
    UnlockFailed

but the Nano cannot reliably determine the underlying physical cause.

The independent watchdog system may later provide additional diagnostic
coverage.

---

# 10. Test requirements

Each fault requires tests for:

1. exact trigger condition;
2. transition into `ERROR`;
3. immediate removal of T1/T2 actuation;
4. correct `FaultCode`;
5. no unintended corrective lock/unlock command;
6. persistence while the underlying condition remains;
7. correct auto-clear condition;
8. correct state reconstruction after clearing;
9. equivalent behaviour after controller reset where applicable.

The tests should also verify that all conditions listed in Section 4 remain
non-fault behaviours.

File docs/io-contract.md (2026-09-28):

# Door Controller I/O Contract

Status: Draft v1  
Scope: Arduino Nano motorised-door controller  
Project: Hitchin Hackspace door access system

## 1. Purpose

This document defines the logical interface between the door controller firmware
and the surrounding hardware.

The controller does **not** authenticate RFID cards or make membership/access
decisions.

Credential verification is performed by the existing ESP-RFID system. The door
controller receives an unlock/release request from that system and controls the
motorised Utopic lock so that, as far as practical, the door behaves like a
conventional access-controlled maglock door.

The controller also monitors the physical state of:

- the door;
- the lock bolt;
- the internal exit button;
- the operating-mode key switch.

An optional backup maglock may be added later as a failure-safety device. It is
outside the scope of the initial implementation and initial test suite.

---

# 2. Design principles

The controller shall distinguish between:

1. physical inputs;
2. derived software events;
3. controller state;
4. physical outputs.

The finite state machine shall operate on logical signals/events and shall not
depend directly on Arduino GPIO numbers, electrical polarity, relay wiring, or
other hardware implementation details.

Hardware-specific code shall translate between electrical signals and the
logical interface described here.

---

# 3. Physical inputs

## 3.1 Door closed sensor

Logical name:

    door_closed

Type:

    Boolean level

Meaning:

    true  = door is physically in the closed position
    false = door is not in the closed position

Hardware:

    Magnetic reed switch.

The signal shall be debounced or filtered before being presented to the state
machine.

The electrical polarity at the Arduino input is a hardware-layer detail and
does not affect the logical definition above.

---

## 3.2 Bolt locked sensor

Logical name:

    bolt_locked

Type:

    Boolean level

Meaning:

    true  = mechanical lock bolt is detected in the locked position
    false = lock bolt is not detected in the locked position

Hardware:

    PR12-4DN inductive proximity sensor.

The sensor has an NPN output. Electrical conditioning and signal polarity are
hardware-layer details.

The signal shall be filtered/debounced as necessary before being presented to
the state machine.

The sensor indicates the physical bolt position; it does not indicate whether
the position was reached manually or electronically.

---

## 3.3 RFID release request

Logical name:

    rfid_release

Type:

    Boolean level at the hardware interface.

Source:

    ESP-RFID "Blue Board" access-control system.

Meaning:

    active   = the external access-control system is requesting door release
    inactive = there is currently no RFID/access-system release request

The ESP-RFID system is responsible for credential verification.

The Nano shall not interpret card identifiers or perform membership lookup.

### RFID startup behaviour

An RFID release signal which is already active when the Nano starts shall NOT
be treated as a new access request.

At startup:

1. sample the RFID release input;
2. if it is inactive, arm RFID request detection immediately;
3. if it is active, ignore it;
4. remain disarmed until the signal returns inactive;
5. after it has returned inactive, arm the input;
6. the next inactive-to-active transition is a valid RFID release request.

Conceptually:

    boot
      |
      +-- RFID inactive --> armed
      |
      +-- RFID active ----> wait for inactive --> armed

This prevents the remaining portion of an ESP-RFID timed output pulse from
being interpreted as a new access event following a controller restart.

---

## 3.4 Internal exit button

Logical name:

    exit_button

Type:

    Boolean level

Meaning:

    active   = internal exit button is being pressed
    inactive = internal exit button is not being pressed

The exit button is electrically separate from the RFID release request and must
remain logically separate in the firmware.

Unlike the RFID release input, an exit button which is already pressed during
controller startup SHALL be honoured.

Therefore:

    boot + exit_button active

may initiate an unlock operation immediately, subject to normal state-machine
safety rules.

The exit button is intentionally given different startup semantics from the
RFID release input.

---

# 4. Operating mode inputs

The controller shall support three operator-selected modes:

    Disabled
    Standard
    OpenNight

The intended hardware is a three-position key switch.

The current design assumption is that each position will have its own Nano
input:

    mode_disabled
    mode_standard
    mode_open_night

Exactly one mode input shall normally be active.

The logical representation used by the state machine shall be:

    enum class OperatingMode {
        Disabled,
        Standard,
        OpenNight,
        Invalid
    };

The hardware layer shall convert the three input lines into this enumeration.

## 4.1 Valid combinations

    Disabled     Standard     OpenNight       Result
    ------------------------------------------------
    active       inactive     inactive        Disabled
    inactive     active       inactive        Standard
    inactive     inactive     active          OpenNight

Any other combination shall produce:

    OperatingMode::Invalid

Examples include:

    no input active
    two inputs active
    all three inputs active

These conditions may indicate:

- disconnected wiring;
- shorted wiring;
- switch failure;
- incorrect installation.

The final electrical implementation of the key switch is TBD.

---

# 5. Physical outputs

## 5.1 Lock command

Logical command:

    Lock

Hardware action:

    energise the appropriate PCB relay so that T1 on the Utopic 433 MHz
    interface is held LOW.

The command shall remain asserted for the entire LOCKING state.

It shall cease when:

- the bolt sensor confirms that the bolt is locked; or
- the locking attempt times out; or
- the FSM otherwise leaves the LOCKING state.

The Utopic lock controller itself is responsible for stopping its motor at the
end of travel.

The Nano does not directly control motor current or motor end stops.

---

## 5.2 Unlock command

Logical command:

    Unlock

Hardware action:

    energise the appropriate PCB relay so that T2 on the Utopic 433 MHz
    interface is held LOW.

The command shall remain asserted for the entire UNLOCKING state.

It shall cease when:

- the bolt sensor confirms that the bolt is unlocked; or
- the unlocking attempt times out; or
- the FSM otherwise leaves the UNLOCKING state.

The Utopic lock controller itself is responsible for stopping its motor at the
end of travel.

---

## 5.3 No command

Logical command:

    None

Meaning:

    neither the T1 nor T2 relay is commanded.

The controller output shall be represented internally as one mutually-exclusive
value:

    enum class LockCommand {
        None,
        Lock,
        Unlock
    };

It shall therefore be impossible for the FSM to request LOCK and UNLOCK
simultaneously.

---

# 6. Relationship between states and lock outputs

The normal mapping is:

    FSM state             Lock command
    -----------------------------------
    LOCKING               Lock
    UNLOCKING             Unlock
    all other states      None

The command is therefore predominantly a property of the current transient
state rather than a momentary action generated on state entry.

This rule may later be extended if a specific fault-recovery procedure requires
otherwise.

---

# 7. Optional backup maglock

A backup maglock has been considered as a possible safety/failure-response
device.

It is not required for the first implementation.

The initial FSM and test suite shall therefore not require a maglock output.

Provision may be left in the architecture for a future output such as:

    backup_maglock

but its behaviour is explicitly outside the scope of v1.

---

# 8. Derived events

The hardware/input layer may convert physical signal changes into events for
the FSM.

Expected derived events include:

    DOOR_OPENED
    DOOR_CLOSED

    BOLT_LOCKED
    BOLT_UNLOCKED

    RFID_RELEASE_REQUEST
    EXIT_BUTTON_REQUEST

    MODE_DISABLED
    MODE_STANDARD
    MODE_OPEN_NIGHT
    MODE_INVALID

and timer-generated events such as:

    LOCK_TIMEOUT
    UNLOCK_TIMEOUT
    AUTO_LOCK_TIMEOUT
    OPEN_TIMEOUT
    MAX_OPEN_TIMEOUT

The exact event representation will be defined with the FSM transition table.

---

# 9. Manual operation

Manual operation of the physical lock is permitted.

A change in the bolt sensor must therefore not automatically be considered a
fault merely because no electronic lock/unlock command was being issued.

For example:

    LOCKED_CLOSED
        bolt_locked changes true -> false

may represent:

    manual unlock

and can result in transition to:

    UNLOCKED_CLOSED

Likewise:

    UNLOCKED_CLOSED
        bolt_locked changes false -> true

may represent:

    manual lock

and can result in transition to:

    LOCKED_CLOSED

Whether a particular manually-created state requires subsequent corrective
action is defined by the FSM, not by the input layer.

---

# 10. Sensor consistency

The following sensor combination is intrinsically suspicious:

    door_closed = false
    bolt_locked = true

The bolt position is only reliably meaningful when the door is aligned with the
frame.

This combination therefore indicates that:

- one sensor may be faulty;
- wiring may be faulty;
- a mechanically abnormal condition may exist.

The FSM shall treat this combination as a fault condition rather than blindly
attempting corrective lock movement.

Detailed fault behaviour will be defined separately.

---

# 11. Startup behaviour

On startup the controller shall first establish the physical condition of the
door rather than assume that the pre-reset FSM state is known.

Transient states such as:

    LOCKING
    UNLOCKING

cannot be reconstructed following a reset because the controller no longer
knows whether a command had previously been in progress.

The startup sequence shall therefore be:

1. initialise outputs to `LockCommand::None`;
2. initialise GPIO and input conditioning;
3. read the operating-mode inputs;
4. establish stable door and bolt sensor values;
5. initialise RFID request arming state;
6. inspect the exit-button state;
7. reconstruct the appropriate stable physical/FSM state;
8. apply normal FSM policy from that state.

No T1 or T2 command shall be asserted merely because the controller has booted.

---

# 12. Startup state reconstruction

The basic physical states are reconstructed from:

    door_closed
    bolt_locked

as follows:

    door_closed    bolt_locked     reconstructed condition
    ------------------------------------------------------
    true           true            LOCKED_CLOSED
    true           false           UNLOCKED_CLOSED
    false          false           UNLOCKED_OPEN
    false          true            sensor/physical fault

The operating mode is then applied.

---

# 13. Startup policy

The general design principle is:

> After reconstructing its physical state, the controller should behave as
> though it had already been running in that state.

Startup should not normally introduce special state transitions.

Known exceptions are listed below.

## 13.1 RFID release active at boot

An RFID request already active at startup shall be ignored until the signal
first becomes inactive.

It must not initiate an electronic unlock.

This is deliberately different from normal running behaviour.

## 13.2 Exit button active at boot

An exit button which is physically pressed during startup shall be honoured.

If the door is locked and normal safety conditions permit unlocking, the
controller may enter UNLOCKING.

## 13.3 Closed and unlocked at boot

If startup finds:

    door_closed = true
    bolt_locked = false
    mode = Standard
    no valid unlock request

the controller shall attempt to lock immediately.

It shall not wait for the normal `auto_lock_time`.

This is deliberately different from entering UNLOCKED_CLOSED during normal
operation.

## 13.4 Door open at boot

If startup finds:

    door_closed = false
    bolt_locked = false

the controller shall reconstruct:

    UNLOCKED_OPEN

and shall not attempt to lock while the door remains open.

Normal policy resumes after the door closes.

## 13.5 Contradictory sensors at boot

If startup finds:

    door_closed = false
    bolt_locked = true

the controller shall enter the appropriate fault handling.

It shall not blindly command the lock motor.

---

# 14. Disabled mode

`Disabled` is an explicit operator-selected mode.

The exact transition behaviour on:

    entering Disabled
    leaving Disabled
    changing mode while the door is open
    changing mode while locked/unlocked

will be defined in the state-transition specification.

The input contract only guarantees that the FSM receives an unambiguous
`OperatingMode`.

---

# 15. Standard mode

`Standard` is the normal access-controlled operating mode.

Detailed values such as:

    auto_lock_time
    open_timeout
    lock_time
    unlock_time
    max_lock_attempts
    max_unlock_attempts

are controller configuration values and are not part of the physical I/O
contract.

---

# 16. Open Night mode

`OpenNight` permits the door to remain unlocked for substantially longer than
normal Standard operation.

The exact timing and state-transition behaviour will be defined by the FSM
specification.

Selection is via the three-position operator key switch.

---

# 17. Diagnostics

Diagnostics are separate from primary door control.

The controller should make internal status available in a form equivalent to:

    struct ControllerStatus {
        State state;
        FaultCode fault;
        uint8_t lock_attempts;
        uint8_t unlock_attempts;
    };

Possible consumers include:

- local LEDs;
- serial diagnostics;
- an independent watchdog;
- an external monitoring/email system.

A failure in the diagnostic system shall not be required for correct normal
door-control operation.

The exact diagnostic hardware interface is outside the scope of this document.

---

# 18. Hardware abstraction boundary

The state-machine/controller layer shall not directly depend on:

    digitalRead()
    digitalWrite()
    Arduino pin numbers
    active-high/active-low GPIO details
    relay wiring
    sensor electrical interface details

A hardware-specific layer shall convert between those details and logical
values approximately equivalent to:

    struct Inputs {
        bool doorClosed;
        bool boltLocked;

        bool rfidRelease;
        bool exitButton;

        OperatingMode mode;
    };

and:

    struct Outputs {
        LockCommand lockCommand;
    };

This permits the controller logic to be compiled and tested on a host computer
without Arduino hardware.

---

# 19. Items deliberately left for later specifications

The following are not required to complete this I/O contract:

- complete FSM transition table;
- exact timeout values;
- retry counts;
- complete fault catalogue;
- local LED behaviour;
- watchdog/email behaviour;
- backup-maglock behaviour;
- Arduino GPIO-number assignment;
- electrical active-high/active-low definitions;
- key-switch contact wiring;
- test implementation.

These belong in subsequent design documents.

---

# 20. Outstanding hardware details

The following should be recorded when confirmed:

- Nano pin used for each physical input;
- Nano pin used for each relay output;
- electrical polarity of each Nano input;
- required input pull-ups/pull-downs;
- exact relay polarity;
- exact three-position key-switch wiring;
- input debounce/filter values;
- actual ESP-RFID relay pulse duration configured on the installed Blue Board.

None of these alter the logical I/O definitions in this document.

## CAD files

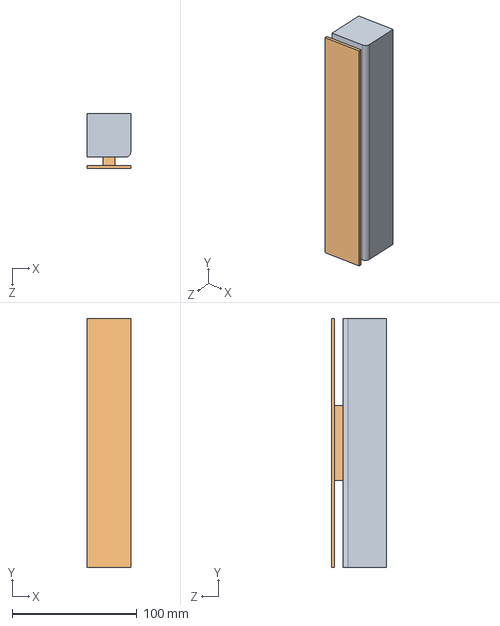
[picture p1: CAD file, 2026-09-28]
mechanical/door detail with lock sensor.STEP
35.0 x 200.0 x 44.3 mm
door lock detail
SN04-N

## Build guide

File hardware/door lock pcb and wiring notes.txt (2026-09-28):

gs-sh-212d relays
uln2803a Darlington driver   -inverting

yellow and blue outputs go to the puck
purple goes from puck to blue board

white and white go to other board, to "button"

left hand input side
white/white goes into building (green pair in cat5 (sheathed / one notch) part of lock sensor
pink/pink goes into building (orange pair in cat5 sheathed / one notch)  - door exit button
yellow/yellow goes to green pair unsheathed  (door closed sensor)
pink/pink on green board goes to blue board, third and fourth from bottom
all three are 5V default, ground = signal

3 pole connector with just a single white wire - solid brown, unsheathed ultimately goes to yellow wire to card reader
two notched unsheathed blue goes to yellow to rfid
two notched unsheathed orange goes to white rfid wire

pink/black 2pole green connector, middle of 
pink goes into small board 9-12V unregulated
black goes to small board 
black goes to blue pair in sheathed cable
pink goes to brown pair sheathed

solid orange unsheathed cable goes to small board white (bottom connectors)
solid blue unsheathed cable goes to small board purple (bottom connectors)

sheathed cable is one stripe

box near door
white flat wire - "cctv camera"
exit button:
green and blue connected
red and yellow connected
both connected to orange pair on one stripe

lock sensor
black cable: 
brown - brown pair one notch  (power)
black - single green wire on one notch
blue - blue pair one notch (power) 

card reader

door closed sensor
red and yellow (from black wire out side) to green pair in two notched sheath

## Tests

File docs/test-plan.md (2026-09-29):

# Door controller test plan

Status: pre-bench test plan.

## 1. Automated native tests

Run both Unity suites in CI. Required project-code coverage is 100% lines, 100% functions and at least 88% branches. Tests cover FSM transitions, faults, recovery, retries, debounce, timer deadlines, rollover and same-tick ordering.

Specific regression cases that must remain present include:

- entering `Unlocking` with the bolt already unlocked completes immediately;
- release during `Locking` is queued until lock completion/timeout and then wins;
- release during `LockRetryWait` suppresses the next lock retry;
- Disabled startup never actuates, including contradictory sensor levels;
- a centre-off mode transition shorter than 1000 ms is not published as Disabled;
- lock retries use 1/10/100/1000/10000 s back-off and end in `LockFailed`;
- Open Night permits up to two hours continuously open;
- present physical contradictions update the reported fault while already in `Error`;
- all timers remain correct across `uint32_t`/`millis()` wraparound;
- the degraded FAULT indication activates after the second failed lock attempt
  and clears on a later successful lock.

Controller/wrapper tests in the same canonical plan cover raw-input debounce,
RFID boot disarm/re-arm, held-exit startup handling, mode settling, exact timer
deadlines, stale-timer cancellation, sensor-vs-timer same-tick ordering, retry
back-off and rollover behaviour. `docs/test-plan.md` is the single maintained
test-plan document.

## 2. Target compile

CI must separately compile the complete sketch for the classic ATmega328P Arduino Nano using the pinned Arduino AVR core and Embedded Template Library ETL release. Host compilation is not a substitute for this check.

## 3. Bench test before connecting the lock

With relay contacts unloaded, verify input polarity and stable interpretation for door reed, bolt sensor, RFID, exit button and all key-switch positions. Verify A3/A2 relay direction and confirm neither relay is energised during reset/startup.

Measure the relay contacts or HAI T1/T2 inputs during direct reversals and during Lock -> None -> Unlock / Unlock -> None -> Lock sequences. There must be at least 250 ms from actual release of one direction before the opposite command energises.

Confirm startup proceeds after approximately 2 s even with a deliberately chattering input. Confirm the FAULT relay activates after the second failed lock attempt while background retries continue. Optional `DOOR_SERIAL_DIAGNOSTICS=1` output may be used during this bench work.

## 4. Bench test with HAI/Utopic connected

Verify one complete successful lock and unlock, then deliberately suppress the expected bolt sensor confirmation to exercise timeout/retry behaviour. Confirm T1/T2 are released during every retry wait. During an active lock attempt, inject an RFID/exit request and confirm it is queued: no additional lock retry is started, and a real unlock command follows lock confirmation or timeout.

Before deployment, determine the HAI command contract (edge/level behaviour, minimum pulse, JP1 setting, and behaviour if T1+T2 are both asserted) and the Utopic behaviour on command reversal.

## 5. Startup matrix

Exercise every relevant combination of mode, door level, bolt level, held exit and RFID-active-at-boot. At minimum, automate the 4 x 2 x 2 x 2 x 2 matrix and assert state, fault and motor command. RFID-active-at-boot must never count as a fresh release.

## 6. Further robustness tests

Before deployment, add a small simulated plant model in which bolt state follows lock/unlock commands after a delay, plus a deterministic seeded random walk over raw inputs and time. Assert output invariants on every tick.

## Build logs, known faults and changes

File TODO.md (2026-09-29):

# TODO

## Hardware changes / decisions

- [ ] Replace existing key switch with three-position maintained key switch
- [x] Allocate Nano inputs for the three operating modes using two signals:
      D8 = Standard, D9 = Open Night, neither = Disabled, both = Invalid
- [ ] Confirm the exact contact/wiring arrangement of the purchased key switch
      matches the active-low `INPUT_PULLUP` scheme
- [ ] Update DipTrace schematic for the new key-switch wiring
- [ ] Confirm/configure ESP-RFID unlock pulse duration
- [ ] Decide whether to fit backup maglock
- [ ] If fitted, design backup-maglock interface and failure behaviour
- [ ] Design independent watchdog / monitoring system
- [x] Drive existing FAULT relay for FSM faults and degraded extended lock retry

## FSM / behaviour

- [ ] Update the FSM diagram to distinguish RFID release from exit-button release
- [x] Implement Disabled / Standard / Open Night operating modes
- [x] Implement invalid key-switch state handling
- [x] Define and implement startup reconstruction for current physical states
- [x] Ignore RFID release already active at boot until it clears
- [x] Honour exit button if held during boot when electronic control is enabled
- [x] Define and implement manual lock / unlock behaviour
- [x] Define and implement contradictory door/bolt sensor handling
- [x] Define behaviour when a release request remains active
- [x] Define Standard-mode auto-lock timing: 5 s
- [x] Define current Open Night timing: 2 h
- [x] Define lock timeout: 5 s
- [x] Define unlock timeout: 5 s
- [x] Define lock retry policy: 5 retries after the initial attempt with 1/10/100/1000/10000 s back-off
- [x] Define maximum unlock retries: 2 after the initial attempt
- [x] Define open warning / maximum-open behaviour: 30 s warning; 5 min Standard fault; 2 h Open Night fault
- [x] Faults auto-clear when the underlying condition is gone and a valid state
      can be reconstructed
- [x] Fault history does not survive controller reset
- [ ] Revisit whether the exit button should remain ignored in Disabled mode
- [ ] Review whether startup reconstruction belongs inside `DoorController` or
      should move into the FSM / a dedicated recovery entry point

## Outputs / actuation

- [x] T1 remains asserted for the complete `Locking` state
- [x] T2 remains asserted for the complete `Unlocking` state
- [x] Lock/unlock outputs are released during retry wait, Disabled and Error
- [x] LOCK and UNLOCK cannot be intentionally asserted simultaneously
- [x] Arduino output adapter enforces 250 ms opposite-direction dead time across intermediate `None` commands
- [ ] Bench-test relay polarity and break-before-make behaviour on a real Nano /
      controller PCB

## Arduino / controller wrapper

- [x] Add thin `door-access-control.ino` hardware adapter
- [x] Add central `src/pin_defs.h`
- [x] Add controller timing/debounce configuration
- [x] Add input debounce layer
- [x] Add RFID boot disarm / re-arm logic
- [x] Add exit-held-at-boot handling
- [x] Add timeout/event generation around the FSM
- [x] Use wrap-safe `uint32_t` timing arithmetic
- [x] Add controller/wrapper native test suite
- [x] Confirm controller/wrapper tests pass in GitHub Actions
- [x] Bring controller/wrapper code back to required coverage thresholds
- [x] Add Arduino Nano compile check in CI
- [x] Compile the complete firmware with the Arduino toolchain
- [ ] Bench-test all physical inputs, FAULT indication and relay outputs before door installation

## Documentation

- [x] Add/update `docs/io-contract.md`
- [x] Add/update `docs/transitions.md`
- [x] Add/update `docs/parameters.md`
- [x] Add/update `docs/invariants.md`
- [x] Add/update `docs/faults.md`
- [x] Add/update `docs/startup-recovery.md`
- [x] Add/update `docs/test-plan.md`
- [x] Consolidate controller/wrapper coverage into canonical `docs/test-plan.md`
- [ ] Store the current editable FSM source plus exported diagram
- [x] Store lock and 433 MHz interface manuals under `reference/lock/`
- [x] Store current access-control system documentation under `reference/`
- [x] Store DipTrace PCB source and schematic exports under `hardware/pcb/`
- [x] Document wiring routes and wire colours
- [x] Document DIN terminal assignments
- [x] Store mechanical CAD for lock installation under `mechanical/lock/`

## Software / testing

- [x] Select ETL `state_chart` as the FSM implementation
- [x] Set up native host tests using Unity
- [x] Vendor Unity test framework in the repository
- [x] Set up GitHub Actions
- [x] Add FSM host-side transition/fault/sequence tests
- [x] Add exhaustive working-state × event safety tests
- [x] Add coverage reporting with LCOV/GCOV
- [x] Enforce 100% line coverage for instrumented project code
- [x] Enforce 100% function coverage for instrumented project code
- [x] Set branch coverage threshold to >= 88% to allow documented unreachable
      compiler-generated short-circuit branches
- [x] Add startup-state tests for the current controller implementation
- [x] Add failure / retry / timeout sequence tests
- [x] Add `millis()` wraparound tests for the controller layer
- [x] Pin ETL used by native and Arduino CI builds to 20.48.1
- [ ] Decide whether Unity should also be version-pinned/documented explicitly
- [x] Add a CI build that verifies the code fits and compiles for Arduino Nano
- [x] Add optional compile-time serial diagnostics for bench testing
- [ ] Add hardware-in-the-loop / bench test procedure before deployment

## Deployment / validation

- [ ] Verify exact installed wiring against `pin_defs.h`
- [ ] Verify key-switch positions electrically
- [ ] Verify door reed polarity
- [ ] Verify PR12-4DN lock sensor polarity and thresholds
- [ ] Verify BlueBoard release polarity and pulse duration
- [ ] Verify exit-button polarity
- [ ] Verify T1 lock direction
- [ ] Verify T2 unlock direction
- [ ] Test every operating mode on bench hardware
- [ ] Test power-up in each relevant physical door/bolt/mode combination
- [ ] Test lock and unlock timeout/retry behaviour on real hardware
- [ ] Test sensor contradiction fault on bench hardware
- [ ] Test recovery from each observable fault
- [ ] Review final firmware and test results before installing on the real door

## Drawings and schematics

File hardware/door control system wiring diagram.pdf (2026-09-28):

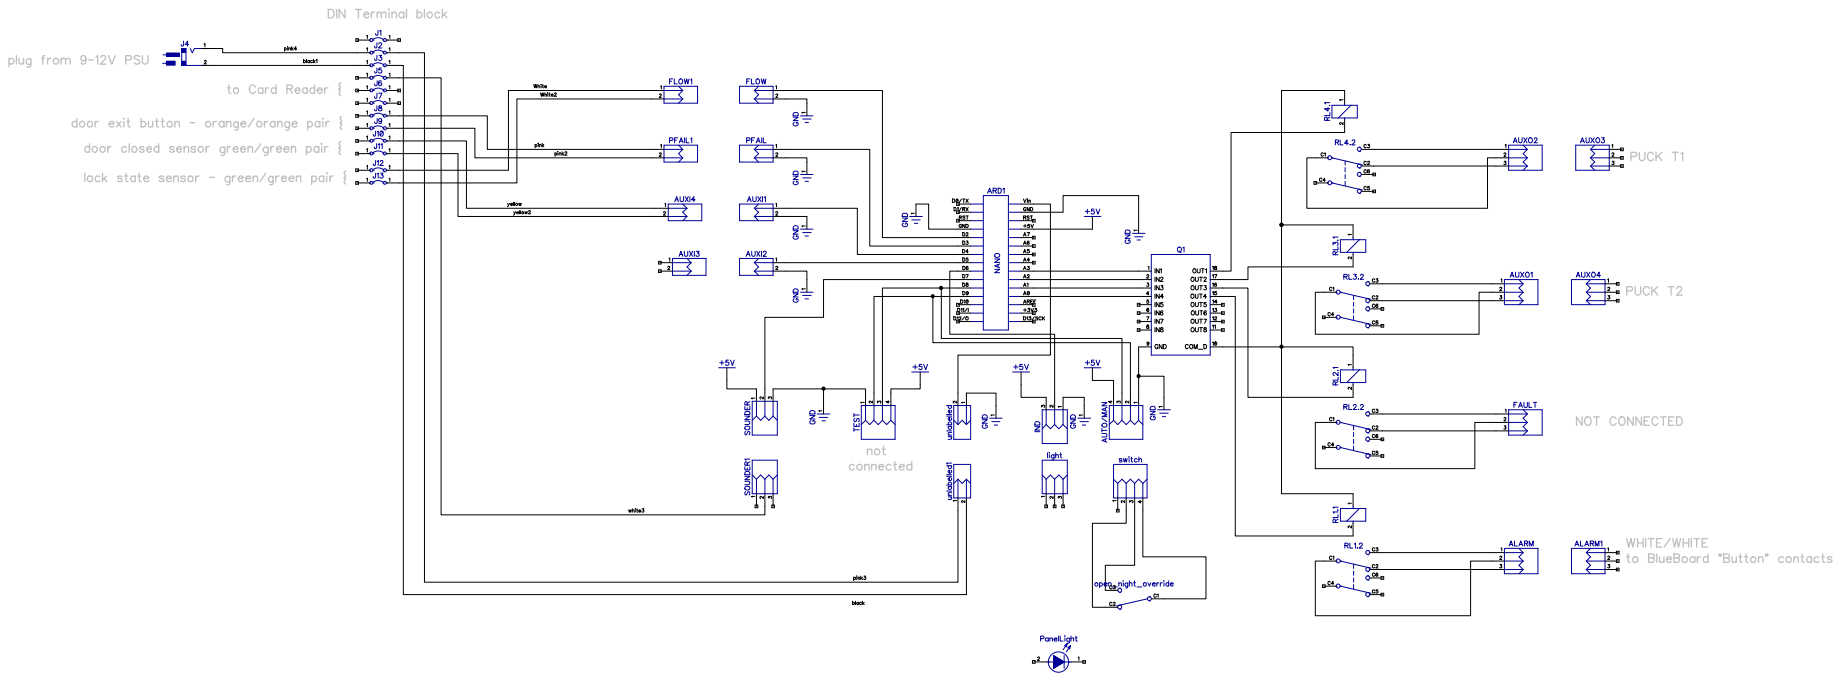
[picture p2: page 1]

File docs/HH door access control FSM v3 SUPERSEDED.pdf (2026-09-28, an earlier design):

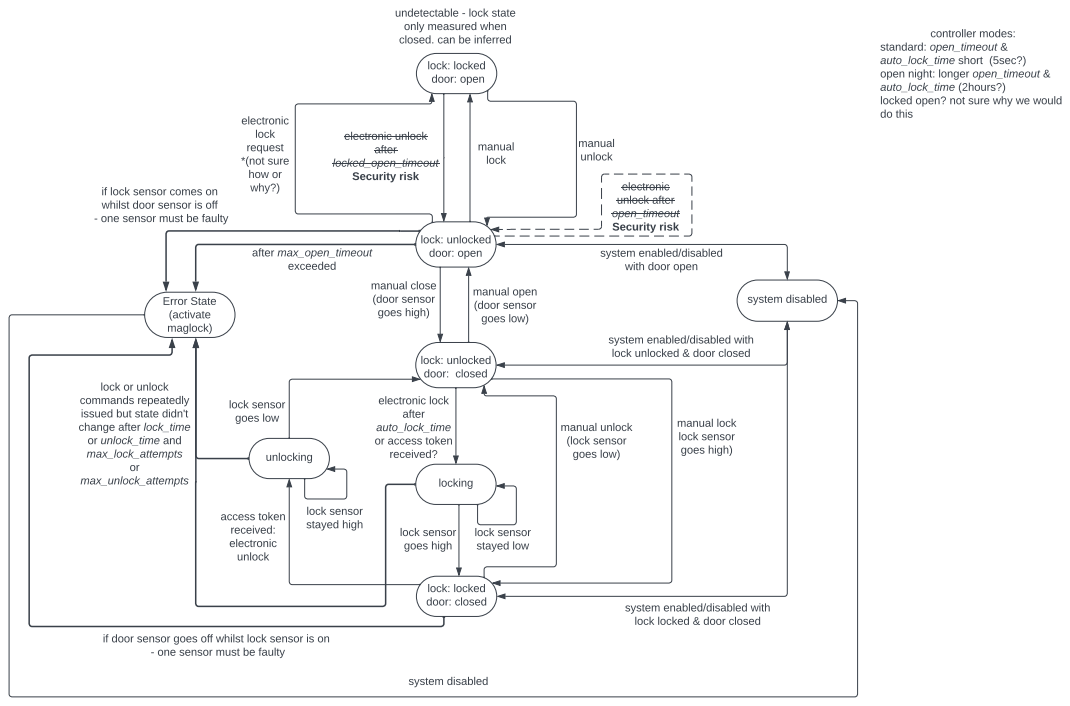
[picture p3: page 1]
system disabled; lock: unlocked door: closed; Error State (activate maglock); lock: unlocked door: open; lock: locked door: closed; lock: locked door: open; manual unlock (lock sensor goes low); manual lock lock sensor goes high); electronic lock after auto_lock_time or access token received?; access token received: electronic unlock; manual open (door sensor goes low); manual lock; manual unlock; electronic unlock after locked_open_timeout Security risk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

undetectable - lock state
only measured when
closed. can be inferred

standard: open_timeout &
auto_lock_time short (5sec?)
open night: longer open_timeout &
auto_lock_time (2hours?)
locked open? not sure why we would
do this

if lock sensor comes on
whilst door sensor is off
- one sensor must be faulty

system enabled/disabled
with door open

system enabled/disabled with
lock unlocked & door closed

lock or unlock
commands repeatedly
issued but state didn't
change after lock_time
or unlock_time and
max_lock_attempts

lock locked & door closed

if door sensor goes off whilst lock sensor is on

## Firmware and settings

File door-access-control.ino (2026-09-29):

#include "src/pin_defs.h"
#include "src/controller_config.h"
#include "src/controller_types.h"
#include "src/door_fsm.h"
#include "src/door_controller.h"

#ifndef DOOR_SERIAL_DIAGNOSTICS
#define DOOR_SERIAL_DIAGNOSTICS 0
#endif

namespace
{

bool activeLow(uint8_t pin)
{
    return digitalRead(pin) == LOW;
}

OperatingMode readOperatingMode()
{
    const bool standardSelected = activeLow(PIN_MODE_STANDARD);
    const bool openNightSelected = activeLow(PIN_MODE_OPEN_NIGHT);

    if (!standardSelected && !openNightSelected) {
        return OperatingMode::Disabled;
    }
    if (standardSelected && !openNightSelected) {
        return OperatingMode::Standard;
    }
    if (!standardSelected && openNightSelected) {
        return OperatingMode::OpenNight;
    }

    return OperatingMode::Invalid;
}

ControllerInputs readInputs()
{
    ControllerInputs inputs;
    inputs.doorClosed = activeLow(PIN_DOOR_CLOSED);
    inputs.boltLocked = activeLow(PIN_LOCK_STATE);
    inputs.rfidActive = activeLow(PIN_CARD_READER_J5);
    inputs.exitPressed = activeLow(PIN_EXIT_BUTTON);
    inputs.mode = readOperatingMode();
    return inputs;
}

bool sameInputs(const ControllerInputs& a, const ControllerInputs& b)
{
    return a.doorClosed == b.doorClosed &&
           a.boltLocked == b.boltLocked &&
           a.rfidActive == b.rfidActive &&
           a.exitPressed == b.exitPressed &&
           a.mode == b.mode;
}

ControllerInputs readStableStartupInputs()
{
    ControllerInputs candidate = readInputs();
    const uint32_t qualificationStartedMs = millis();
    uint32_t stableSinceMs = qualificationStartedMs;

    while (static_cast<uint32_t>(millis() - stableSinceMs) <
               STARTUP_INPUT_STABLE_MS &&
           static_cast<uint32_t>(millis() - qualificationStartedMs) <
               STARTUP_INPUT_TIMEOUT_MS) {
        const ControllerInputs current = readInputs();
        if (!sameInputs(current, candidate)) {
            candidate = current;
            stableSinceMs = millis();
        }
        delay(1);
    }

    // A permanently chattering input must not prevent the controller booting.
    // The normal debouncers and fault handling take over from this sample.
    return candidate;
}

#if DOOR_SERIAL_DIAGNOSTICS
void printDiagnostics(const DoorController& c, uint32_t nowMs)
{
    static uint32_t lastPrintMs = 0;
    if (static_cast<uint32_t>(nowMs - lastPrintMs) < 1000UL) {
        return;
    }
    lastPrintMs = nowMs;

    // Numeric enum values keep the diagnostics small; see controller_types.h.
    Serial.print(F("t="));
    Serial.print(nowMs);
    Serial.print(F(" state="));
    Serial.print(static_cast<uint8_t>(c.state()));
    Serial.print(F(" mode="));
    Serial.print(static_cast<uint8_t>(c.mode()));
    Serial.print(F(" fault="));
    Serial.print(static_cast<uint8_t>(c.fault()));
    Serial.print(F(" indicated="));
    Serial.print(c.faultIndicated() ? 1 : 0);
    Serial.print(F(" cmd="));
    Serial.print(static_cast<uint8_t>(c.lockCommand()));
    Serial.print(F(" door="));
    Serial.print(c.doorClosed() ? 1 : 0);
    Serial.print(F(" bolt="));
    Serial.print(c.boltLocked() ? 1 : 0);
    Serial.print(F(" rfid="));
    Serial.print(c.rfidActive() ? 1 : 0);
    Serial.print(F(" exit="));
    Serial.println(c.exitPressed() ? 1 : 0);
}
#endif

void configurePins()
{
    pinMode(PIN_LOCK_STATE, INPUT_PULLUP);
    pinMode(PIN_EXIT_BUTTON, INPUT_PULLUP);
    pinMode(PIN_DOOR_CLOSED, INPUT_PULLUP);
    pinMode(PIN_CARD_READER_J5, INPUT_PULLUP);

    // Key-switch contacts pull these lines to GND when selected.
    pinMode(PIN_MODE_STANDARD, INPUT_PULLUP);
    pinMode(PIN_MODE_OPEN_NIGHT, INPUT_PULLUP);

    // Safe state before switching the relay-drive pins to outputs.
    digitalWrite(PIN_LOCK_RELAY, LOW);
    digitalWrite(PIN_UNLOCK_RELAY, LOW);
    digitalWrite(PIN_FAULT_RELAY, LOW);
    digitalWrite(PIN_BLUEBOARD_BUTTON, LOW);

    pinMode(PIN_LOCK_RELAY, OUTPUT);
    pinMode(PIN_UNLOCK_RELAY, OUTPUT);
    pinMode(PIN_FAULT_RELAY, OUTPUT);
    pinMode(PIN_BLUEBOARD_BUTTON, OUTPUT);
}

DoorController& controller()
{
    // First called from setup(), after pin configuration.
    // Function-local static avoids heap allocation.
    static const ControllerInputs stableInputs = readStableStartupInputs();
    static DoorController instance(stableInputs, millis());
    return instance;
}

void applyLockCommand(LockCommand command, uint32_t nowMs)
{
    static LockCommand energised = LockCommand::None;
    static LockCommand lastReleased = LockCommand::None;
    static bool releaseTimeValid = false;
    static uint32_t lastReleasedMs = 0;

    if (command == LockCommand::None) {
        digitalWrite(PIN_LOCK_RELAY, LOW);
        digitalWrite(PIN_UNLOCK_RELAY, LOW);

        if (energised != LockCommand::None) {
            lastReleased = energised;
            lastReleasedMs = nowMs;
            releaseTimeValid = true;
            energised = LockCommand::None;
        }
        return;
    }

    if (command == energised) {
        return;
    }

    if (energised != LockCommand::None) {
        // Release the old mechanical relay first. The requested opposite
        // direction is reconsidered on subsequent loop iterations.
        digitalWrite(PIN_LOCK_RELAY, LOW);
        digitalWrite(PIN_UNLOCK_RELAY, LOW);
        lastReleased = energised;
        lastReleasedMs = nowMs;
        releaseTimeValid = true;
        energised = LockCommand::None;
        return;
    }

    // Enforce dead time from the actual release instant, even if one or more
    // explicit None commands occurred between opposite directions. Reasserting
    // the same direction is safe and does not need the delay.
    if (releaseTimeValid &&
        command != lastReleased &&
        static_cast<uint32_t>(nowMs - lastReleasedMs) <
            RELAY_REVERSAL_DEADTIME_MS) {
        digitalWrite(PIN_LOCK_RELAY, LOW);
        digitalWrite(PIN_UNLOCK_RELAY, LOW);
        return;
    }

    if (command == LockCommand::Lock) {
        digitalWrite(PIN_LOCK_RELAY, HIGH);
    } else {
        digitalWrite(PIN_UNLOCK_RELAY, HIGH);
    }
    energised = command;
}

} // namespace

void setup()
{
#if DOOR_SERIAL_DIAGNOSTICS
    Serial.begin(115200);
#endif

    configurePins();

    DoorController& c = controller();
    applyLockCommand(c.lockCommand(), millis());
    digitalWrite(PIN_FAULT_RELAY, c.faultIndicated() ? HIGH : LOW);
}

void loop()
{
    const uint32_t nowMs = millis();

    DoorController& c = controller();
    c.tick(nowMs, readInputs());

    applyLockCommand(c.lockCommand(), nowMs);
    digitalWrite(PIN_FAULT_RELAY, c.faultIndicated() ? HIGH : LOW);

#if DOOR_SERIAL_DIAGNOSTICS
    printDiagnostics(c, nowMs);
#endif
}

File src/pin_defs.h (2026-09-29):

#pragma once

#include <Arduino.h>

// Inputs
constexpr uint8_t PIN_LOCK_STATE      = 2;  // Active-low: PR12-4DN lock-state sensor
constexpr uint8_t PIN_EXIT_BUTTON     = 3;  // Active-low: internal exit button
constexpr uint8_t PIN_DOOR_CLOSED     = 4;  // Active-low: door-closed reed switch
constexpr uint8_t PIN_UNUSED_D5       = 5;
constexpr uint8_t PIN_CARD_READER_J5  = 7;  // Active-low release signal from BlueBoard

// 3-position maintained key switch, centre off.
// Each selected contact is expected to pull its input LOW.
// Neither selected      -> Disabled
// Standard selected     -> Standard
// Open Night selected   -> Open Night
// Both selected         -> Invalid / wiring fault
constexpr uint8_t PIN_MODE_STANDARD    = 8;
constexpr uint8_t PIN_MODE_OPEN_NIGHT = 9;

// Relay outputs.
// HIGH energises the relay, pulling the corresponding Utopic puck input LOW.
constexpr uint8_t PIN_LOCK_RELAY       = A3; // RL4 -> PUCK T1
constexpr uint8_t PIN_UNLOCK_RELAY     = A2; // RL3 -> PUCK T2

// Existing spare/other relay channels.
constexpr uint8_t PIN_FAULT_RELAY      = A1; // RL2 -> FAULT connector (currently unused)
constexpr uint8_t PIN_BLUEBOARD_BUTTON = A0; // RL1 -> BlueBoard "Button" contacts

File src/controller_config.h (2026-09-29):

#pragma once
#include <stdint.h>

constexpr uint32_t AUTO_LOCK_TIME_MS    = 5000UL;
constexpr uint32_t OPEN_TIMEOUT_MS       = 30000UL;
constexpr uint32_t MAX_OPEN_TIMEOUT_MS   = 300000UL;
constexpr uint32_t OPEN_NIGHT_MAX_OPEN_TIMEOUT_MS = 7200000UL;
constexpr uint32_t OPEN_NIGHT_TIME_MS    = 7200000UL;
constexpr uint32_t LOCK_TIME_MS          = 5000UL;
constexpr uint32_t UNLOCK_TIME_MS        = 5000UL;
constexpr uint32_t RETRY_DELAY_MS        = 1000UL; // unlock retries

constexpr uint8_t MAX_LOCK_RETRIES       = 5U;
constexpr uint8_t MAX_UNLOCK_RETRIES     = 2U;
constexpr uint32_t LOCK_RETRY_1_DELAY_MS = 1000UL;
constexpr uint32_t LOCK_RETRY_2_DELAY_MS = 10000UL;
constexpr uint32_t LOCK_RETRY_3_DELAY_MS = 100000UL;
constexpr uint32_t LOCK_RETRY_4_DELAY_MS = 1000000UL;
constexpr uint32_t LOCK_RETRY_5_DELAY_MS = 10000000UL;

constexpr uint32_t DEBOUNCE_DOOR_MS      = 30UL;
constexpr uint32_t DEBOUNCE_BOLT_MS      = 20UL;
constexpr uint32_t DEBOUNCE_RFID_MS      = 10UL;
constexpr uint32_t DEBOUNCE_EXIT_MS      = 30UL;
constexpr uint32_t DEBOUNCE_MODE_MS      = 1000UL;

constexpr uint32_t RELAY_REVERSAL_DEADTIME_MS = 250UL;
constexpr uint32_t STARTUP_INPUT_STABLE_MS     = 100UL;
constexpr uint32_t STARTUP_INPUT_TIMEOUT_MS    = 2000UL;

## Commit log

2026-09-28 first draft of basic FSM, and most of the docs
    [door detail with lock sensor.STEP]
2026-09-28 added arduino code for everything except the existing FSM
2026-09-28 small changes to make the arduino compiler happy
2026-09-29 Fix transient completion when bolt already at target
    [test_controller.cpp]
2026-09-29 Settle key-switch mode changes and keep Disabled authoritative
2026-09-29 Add 250 ms relay reversal dead-time and stable startup sampling
    [controller_config.h, door-access-control.ino]
2026-09-29 Pin ETL and add Arduino Nano compile CI
2026-09-29 Queue release requests while lock operation completes
    A release request can arrive while the Utopic is still completing a previously issued lock command. Treating the current unlocked sensor level as immediate completion can therefore acknowledge the release without ever sending a real unlock command, allowing the lock to finish afterwards and silently re-lock the member out.
    Keep Locking and LockRetryWait active while a release is pending. Complete the lock attempt first, then enter Unlocking when the bolt confirms locked; if the lock attempt times out, honour the pending release instead of starting another lock retry. Apply the same policy to RFID, exit-button and Open Night release reque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
    [test_controller.cpp]
2026-09-29 Bound startup input qualification time
    Startup previously waited forever for all raw inputs to remain unchanged for 100 ms. A chattering sensor, loose connection or noisy key-switch contact could therefore prevent the controller from ever booting.
    Retain the 100 ms stable-input qualification requirement but cap the wait at 2 seconds. If the deadline expires, continue with the most recent sample and allow the normal debouncers and fault logic to handle subsequent changes.
    This avoids a silent permanent boot hang while preserving the intended startup settling period for healthy inputs.
    [controller_config.h, door-access-control.ino]
2026-09-29 Enforce relay dead time across intermediate off states
    The previous break-before-make logic only enforced the 250 ms delay for a direct Lock-to-Unlock or Unlock-to-Lock command change. If a control path inserted a brief None command between opposite directions, that sequence could bypass the protection.
    Track the direction and timestamp whenever an energised relay is actually released, and refuse to energise the opposite relay until the full 250 ms has elapsed. The release timestamp survives intervening None commands, so the safety property no longer depends on current FSM timing assumptions.
    Re-energising the same direction remains immediate because it cannot create T1/T2 overlap.
    [door-access-control.ino]
2026-09-29 Indicate degraded lock state during extended retry backoff
    The extended 1/10/100/1000/10000 second lock retry schedule deliberately keeps trying for more than three hours, but waiting until final LockFailed would leave the space closed-but-unlocked for most of that time without any external indication.
    Expose a controller-level fault indication that is active for every real FSM fault and also after the second failed lock attempt while retries continue. Drive the existing FAULT relay from that indication in both setup and loop.
    A later successful lock clears the retry count and therefore clears the degraded indication automatically. Add a regression test for the threshold and recovery behav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
    [door-access-control.ino, test_controller.cpp]
2026-09-29 Add optional serial diagnostics for bench testing
    Bench commissioning needs a simple way to observe controller state without changing the control path. Add a compile-time diagnostics option that prints one compact status line per second with time, state, mode, fault indication, command and debounced input levels.
    Diagnostics are disabled by default so the deployed build pays no RAM or runtime cost unless explicitly enabled. String literals use Arduino F() storage when enabled to avoid consuming scarce ATmega328P SRAM.
    Enabling USB serial on a live Nano can reset the board via DTR, so this is intended for controlled bench testing rather than permanent production logging.
    [door-access-control.ino]
2026-09-29 Update retry docs and consolidate test plan
    Bring the maintained documentation into line with the post-review behaviour. Document queued release requests during in-flight lock operations, the five-step lock back-off schedule, the separate unlo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
    Make docs/test-plan.md the single canonical test plan and fold the useful wrapper-level coverage expectations into it. Remove the older overlapping wrapper-test-plan.md so maintainers do not have two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
    Also document the optional serial diagnostics and F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
